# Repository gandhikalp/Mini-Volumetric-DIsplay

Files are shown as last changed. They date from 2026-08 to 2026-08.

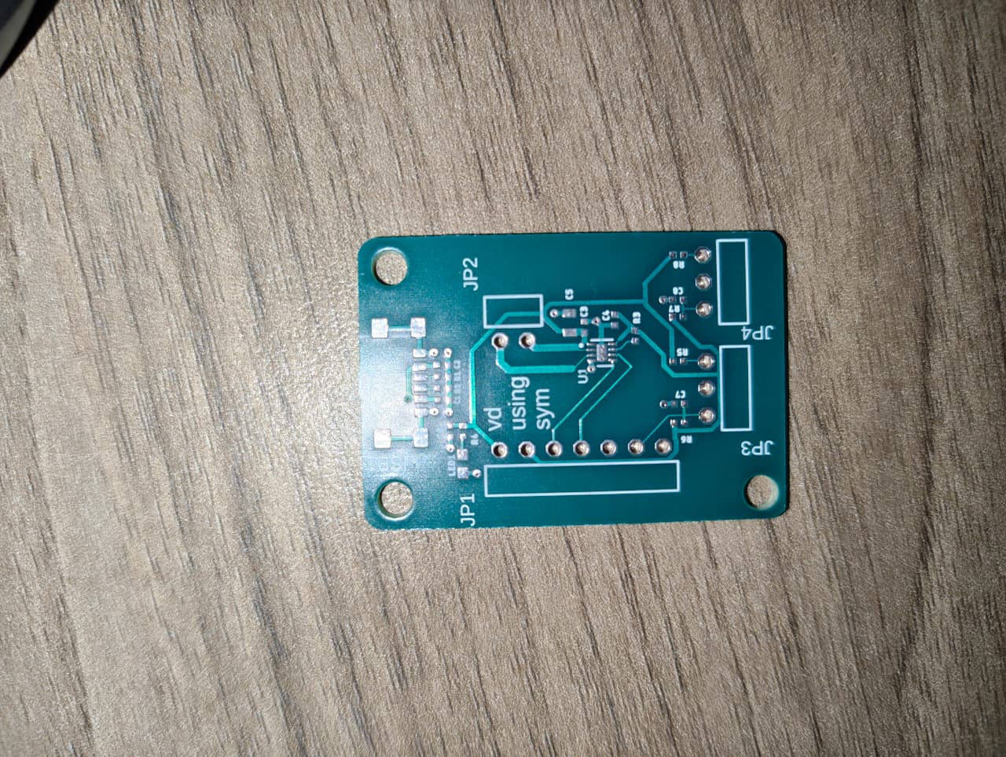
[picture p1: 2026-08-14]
hardware/pcb/Photos/When it arrived after fabrication.jpeg

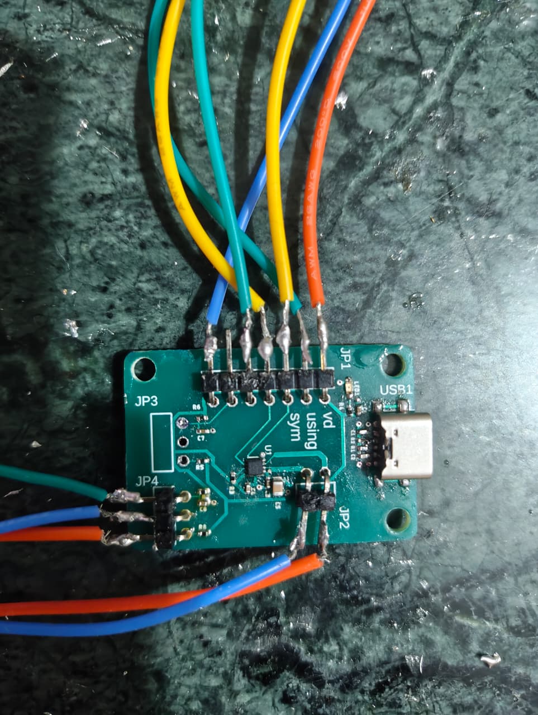
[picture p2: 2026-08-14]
hardware/pcb/Photos/Assembled PCB.jpeg

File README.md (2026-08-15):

# Volumetric Display Prototype

A swept-volume volumetric display built from scratch using a 
scotch yoke mechanism, custom SMT PCB, and Waveshare ESP32-S3-Matrix.

**Status:** Electronics and PCB tested ✅ | Mechanical assembly pending 🔄

> ⚠️ **Note:** This is an active prototype project. Thus, Hardware files and firmware are subject to rapid iterations.
---

## What This Is

A proof-of-concept volumetric display similar in basic principle to the 
Voxon VX1. An 8×8 RGB LED matrix sweeps vertically at ~16Hz 
using a scotch yoke mechanism, creating a 3D persistence-of-vision 
image visible from multiple angles.\
It is highly inspired from [Matthew Lim's video](https://youtu.be/KgT20tHpk1g?si=lmqNyyaOBYBv9zQp) on youtube about mini volumetric display.

---

## Hardware

| Component | Details |
|---|---|
| Microcontroller | Waveshare ESP32-S3-Matrix (8×8 RGB LED matrix) |
| Custom PCB | 2-layer SMT, designed in Fusion 360, fabricated by Lion Circuits |
| Motor | GA12-N20 6V 1000RPM DC motor |
| Motor driver | DRV8838DSGR (on the PCB) |
| Position sensing | Dual ITR-9606 opto interrupters |
| Mechanism | Scotch yoke |
| PCB size | 27.5mm × 40mm |

---

## Firmware Architecture 

Core 0 (real-time):\
→ Motor PWM control via DRV8838\
→ Dual opto interrupt handling\
→ Slice timing calculation

Core 1 (non-critical):\
→ WiFi connection\
→ OTA wireless firmware updates\
→ Web debug dashboard

---

## Current Progress

- [DONE] Custom PCB designed, fabricated, assembled
- [DONE] Motor control verified (3 speeds via PWM)
- [DONE] Dual opto interrupter timing verified
- [DONE] Dual-core firmware with WiFi debug dashboard
- [DONE] OTA wireless firmware updates
- [PENDING] Desgining cad v_2
- [PENDING] Mechanical assembly
- [PENDING] Volumetric slice display firmware

---

## Repository Structure

```text
├── hardware/
│   ├── pcb/               # Gerber Files, BOM, schematic, PCB photos
│   └── cad/        
│       ├── failed_design/     # First design + notes on why it failed
│       └── current_design/    # Current redesigned mechanism
├── firmware/              # Arduino IDE sketches
├── build_log/                  # Build log, images
└── references/            # Inspiration and related work
```
---

## PCB

Custom 2-layer controller board handling:
- USB-C power input with proper CC resistor negotiation(5.1k ohms resistors)
- DRV8838DSGR motor driver (1.8A capable)
- Dual opto interrupter interface circuits
- 7-pin interface to ESP32 board
- Status LED

Fabricated by Lion Circuits, India.

---

## Why **Scotch Yoke** Mechanism?

Unlike rack-and-pinion (used in Matthew Lim's build) and slider crank mechanism (which also used for converting circular motion into linear reciprocating motion), 
Scotch Yoke produces Simple Harmonic Motion:
- Screen dwells longer at extremes → better brightness distribution
- No backlash at direction reversal
- Smoother reversal → lower vibration
- Mathematically clean position from sin(angle)

---

## Build Log

See [build_log.md](build_log/build_log.md)

---

## Related Work

- [Matthew Lim's mini volumetric display](https://youtu.be/KgT20tHpk1g?si=lmqNyyaOBYBv9zQp)
- [Voxon Photonics VX1/VX2](https://voxon.co)

---

## Author

Gandhi Kalp — 2nd year B.Tech Civil Engineering, IIT ISM Dhanbad  
Interests: Robotics, Embedded Systems, IoT, ML and Automation

Check my [LinkedIn](https://www.linkedin.com/in/gandhikalpniravkumar/?skipRedirect=true)

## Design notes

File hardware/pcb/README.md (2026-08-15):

# PCB of Mini VLD using SYM

Think of this custom PCB as the central hub of the project. It sits directly between the power supply, the DC motor, the optical sensors, and the ESP32-S3. 

By taking care of all the messy power routing and distribution, it lets the ESP32 just sit back and focus entirely on the computation. It also features an onboard DRV8838 motor driver. Since the ESP32 can only output weak, low-voltage instructions, it takes all logic signals and then safely delivers the required high current to spin the motor.

---

## Technical Specifications

| Parameter | Specification |
| :--- | :--- |
| **Project Name** | vd_using_sym |
| **Dimensions** | 27.5 mm × 40.0 mm |
| **Layer Count** | 2 Layers |
| **Thickness** | 1.6 mm |
| **Substrate** | FR4 (Tg 130°C) |
| **Solder Mask** | Green |
| **Silkscreen** | White (Single Side) |
| **Surface Finish** | HASL |
| **Fabricator** | Lion Circuits (India) - IPC Class 2 |

---

## System Architecture

The board takes 5V from the USB-C port to directly power the motor driver and the ESP32-S3. To save space, it does not use an onboard 3.3V regulator. Instead, the ESP32 sends regulated 3.3V *back* to the mainboard to power the logic, sensors, and status LED.

```mermaid
graph TD
    USB[USB-C 5V] --> 5V_RAIL[5V Rail]
    5V_RAIL --> DRV[DRV8838 Driver]
    5V_RAIL --> ESP[Waveshare ESP32-S3]
    
    ESP -->|3.3V Return| 3V3_RAIL[3.3V Rail]
    3V3_RAIL -->|Logic Power| DRV
    3V3_RAIL -->|Logic Power| SENSORS[Opto Sensors]
    
    ESP -->|Motor Control| DRV --> MOTOR[N20 DC Motor]
    SENSORS -->|Timing Interrupts| ESP
```
---
## Hardware Pinout Map

### Main Header (`JP1` — 7-Pin Interconnect)
*Connects the PCB to the moving Waveshare ESP32-S3 board.*

| Pin # | Label | Direction | Target | Function |
| :---: | :--- | :---: | :--- | :--- |
| **1** | `GND` | Power | System Ground | Common Ground Reference |
| **2** | `O1` (OPTO1) | Output | `GPIO4` | Top Dead Centre (TDC) Trigger |
| **3** | `O2` (OPTO2) | Output | `GPIO5` | Bottom Dead Centre (BDC) Trigger |
| **4** | `MOTOR_DIR` | Input | `GPIO6` | Motor Direction Control |
| **5** | `MOTOR_PWM` | Input | `GPIO7` | Motor Speed Control |
| **6** | `+3.3V` | Input | 3.3V Rail | 3.3V **returned** from Waveshare LDO |
| **7** | `+5V` | Output | 5V Rail | Main 5V Supply to Waveshare |
---

## Key Design Features

*   **Efficient Motor Control:** Uses a tiny DRV8838 driver to deliver maximum power to the motor without wasting voltage or generating excess heat.

*   **Hardware Debouncing:** An onboard filter (using 100nf capacitor and 10kohms resistor) physically smooths out messy sensor signals before they reach the ESP32.

*   **Safe Sensor Logic:** Sensor voltages are tied to 3.3V, protecting the ESP32 pins from any damage.

*   **Power-Only USB-C:** Dedicated strictly to 5V power delivery.

---
## Testing & Validation

The Board has been fully assembled and all the components are tested also.

*   ✅ **Power Rail:** 5V successfully delivered to the motor driver and ESP; status LED active.
*   ✅ **Logic Control:** 3.3V successfully returning from the ESP to power the logic layer.
*   ✅ **Motor Control:** DRV8838 driving the N20 motor at variable PWM speeds with forward/reverse direction control.
*   ✅ **Sensor Interrupts:** Opto-interrupters triggering clean, hardware-debounced signals on the ESP pins.

---

## Manufacturing & Assembly

All necessary files to fabricate and assemble this board are located in the [Manufacturing files](./Manufacturing%20files/) folder:

*   **Gerbers & NC Drill Files:** Ready for standard 2-layer fabrication.
*   **BOM (Bill of Materials):** Complete list of passives, headers, and ICs.

> **Next Step:** To see the C++ code that runs on the ESP32-S3 board to test this PCB, head over to the [Firmware Directory](../../firmware/).
---

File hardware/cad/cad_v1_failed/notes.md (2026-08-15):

# CAD v1 — Design Failures and Lessons Learned

This folder preserves the first mechanical design iteration.
And i really believe that documenting failures is as important as documenting successes.
These are the exact problems found and the decisions made.

---

## Failure 1 — Wire Routing Holes Too Small

### What Was Designed
Small rectangular holes were made to fit in the opto interruptors but they were small that the wires wouldn't go in them.

### What Was Wrong
The hole area was insufficient for:
- The opto interrupter body to pass through for mounting
- Multiple silicone wires to route cleanly together

The opto interrupters (ITR-9606) could not be inserted
through the holes into their mounting brackets as intended.
Wires had to be forced through, risking insulation damage
at the sharp hole edges.

### Root Cause
Holes were sized purely for physical dimensions of the opto interruptor without
accounting for:
- Wire diameter
- Wire bundle diameter when multiple wires grouped together
- Assembly clearance needed during build

### To be fixed In v2
- Opto mounting holes enlarged to fit ITR-9606 body with
  0.5mm clearance on each side
- Take in account for the diameter of the wires also

---

## Failure 2 — Bottom Linear Guide Too Short (Yoke Escape)

### What Was Designed
Two rectangular guide blocks — one at top, one at bottom
of the frame — to constrain the yoke slider to vertical
motion only. The yoke has rectangular rails that slide
through these guide blocks.

### What Was Wrong
The bottom guide block was too short in the vertical
direction. At the top of the yoke's travel stroke,
the bottom rails of the yoke slider exited the bottom
guide block completely. Once outside the guide, the
yoke had no constraint at the bottom — it began to
wobble and rotate around the crank pin axis.

Specifically:
- Bottom guide block height: too short
- Bottom rail fully
  exited guide block → zero constraint → wobble

### Why This Wasn't Caught In Simulation
The joints in Fusion 360 were set up to only allow
vertical slider motion regardless of physical geometry.
The simulation showed correct motion because the joints
enforced it mathematically — not because the geometry
actually constrained it.

Real-world: once the rail exits the block, no constraint.
Simulation: joint still enforces linear motion regardless.

This is the difference between kinematic simulation
and real mechanical constraint.

### Root Cause
Failure to verify that the guide block remained engaged
with the rail throughout the FULL stroke of travel.

The check that was missed:
Does any part of the rail remain outside
the guide block during the motion? Answer was **YES** for the bottom block.

### The Rule This Establishes
Guide block must remain engaged with rail by at least
one full block-length at every point in the stroke.

Minimum rail length below slot =
  bottom guide block height
  + full stroke length (20mm)
  + safety margin (5mm)  
  = 25mm minimum

### To be fixed in v2
- Bottom guide block height increased significantly
- Rail length extended downward to maintain engagement
  at full top-dead-centre position
- Added explicit check in Fusion: at top of stroke,
  measured remaining rail inside guide block
  Result: 8mm still engaged at worst case ✅
- Added fillet at guide block entry to smooth
  any edge contact at extreme positions

---

## Summary Table

| Failure | Component | Root Cause | Fix To Be Applied |
|---|---|---|---|
| Holes too small | Wire/opto routing | No clearance for wire diameters | Enlarged holes |
| Yoke escapes guide | Bottom guide block | Guide too short for full stroke | Longer block + longer rails |

---

## Key Lessons
- Always check mechanism at EXTREME positions
not just the neutral/mid position.
- Fusion joints enforce motion mathematically
Real geometry must also enforce it physically. 
- Simulate ≠ works in real life
- Any hole a component passes through needs
component dimension + clearance.
- Size consideration should be done for wire diameter also.
- For sliding mechanisms: Engagement length remaining at worst case
must be verified explicitly before printing
---
### What Was Preserved Here

The original Fusion 360 design files (`.f3d` and `.step`) are included in this folder for archival purposes, but they have been entirely **SUPERSEDED** by v2.

What is preserved in this document:
- This written failure analysis
- The specific measurements that were wrong
- The design decisions made as a result
- The lessons applied to v2

### Failure documentation is part of the engineering record. Version 2 exists because version 1 failed and was analyzed honestly. 
---

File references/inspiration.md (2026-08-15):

# References & Inspiration

This prototype was built on the foundation of existing research, open-source projects, and technical documentation in the volumetric display technology. 

## Primary Inspiration

   *   [Watch Matthew Lim's Video Here](https://youtu.be/KgT20tHpk1g?si=lmqNyyaOBYBv9zQp)

## Commercial Products

*   **Voxon Photonics (VX1 & VX2):** The industry pioneers in swept-volume volumetric displays, serving as the ultimate benchmark for mechanical persistence-of-vision (POV) 3D technology. 
    *   **VX1:** The original flagship model that proved the concept, utilizing a linear reciprocating (up-and-down) screen paired with an ultra-fast DLP projector. 
    *   **VX2:** A massive architectural upgrade over the VX1. Instead of a bouncing screen, the VX2 relies on a high-speed rotating LED matrix (VLED Engine) that spins at 900 RPM. This rotational concept is vastly superior, allowing the machine to run quieter, scale larger, and generate up to 8 million voxels while refreshing 30 full 3D volumes every second.

## Technical References & Datasheets

I referenced official datasheets to calculate component values and verify power limits for the custom PCB. Copies of these files are saved in the [Datasheets directory](../hardware/Datasheets_of_major_components_used/). 

*   **Waveshare ESP32-S3-Matrix:** Used for GPIO pinouts, onboard 3.3V LDO specs, and LED matrix timing. Here's the link for it => [Waveshare ESP32-S3 Matrix](https://docs.waveshare.com/ESP32-S3-Matrix)
*   **Texas Instruments DRV8838:** Used to check motor driver power limits and bypass capacitor requirements.
*   **Everlight ITR-9606 Opto-interrupter:** Used to calculate the 100Ω current-limiting resistor for the IR LED.

## Tools Used

*   **Autodesk Fusion 360:** Used for both mechanical 3D modeling of the Scotch Yoke mechanism and the 2D schematic/PCB layout.

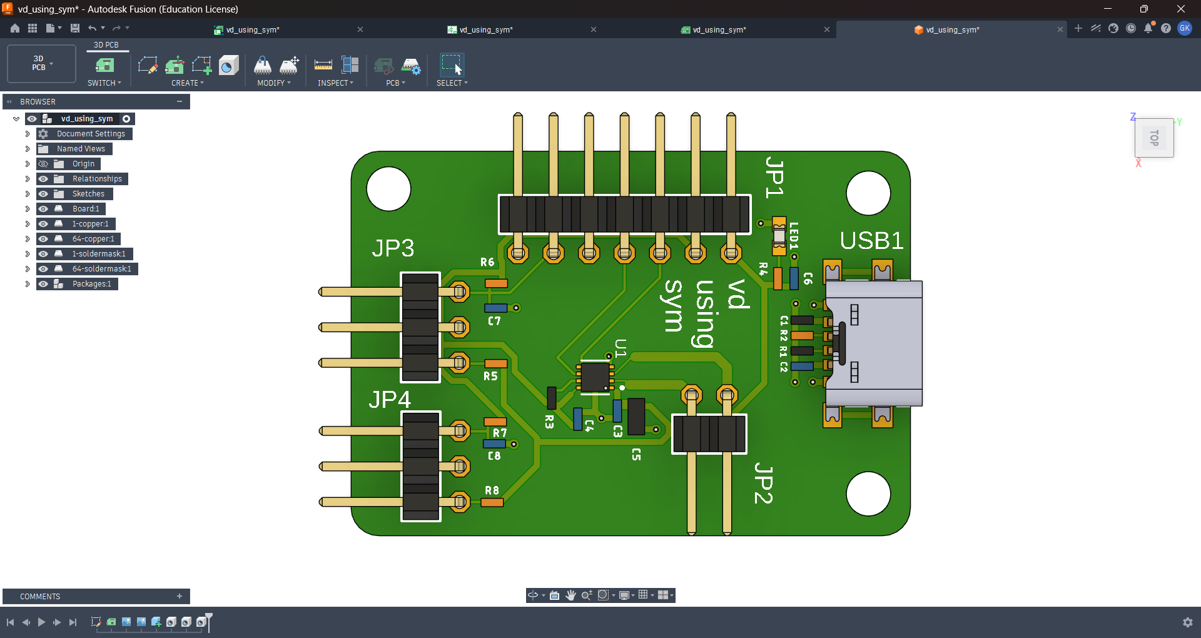
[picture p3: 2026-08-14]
hardware/pcb/Photos/frontside_of_pcb.png

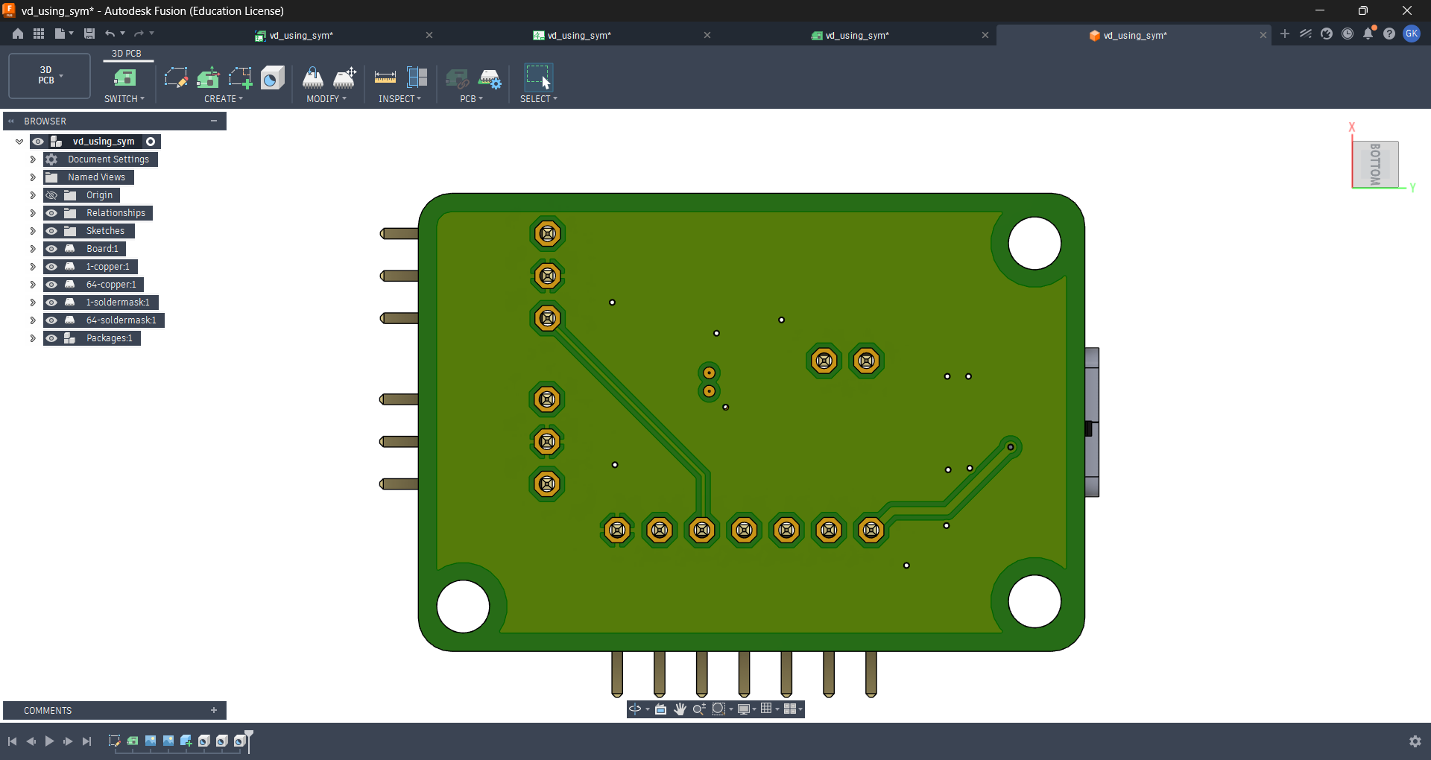
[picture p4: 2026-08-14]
hardware/pcb/Photos/backside_of_pcb.png

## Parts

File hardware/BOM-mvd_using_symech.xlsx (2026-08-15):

NAME | LINK | PRICE FOR SINGLE UNIT( in Rupees) | QTY | FINAL PRICE(inc gst and shipping charges)(in Rupees) | REMARK | USED/ NOT USED
Waveshare ESP32-S3 Development Board, Onboard 8×8 RGB LED Matrix and QMI8658C Attitude Sensor, Supports Wi-Fi and Bluetooth LE, ESP32 Development Board | https://robu.in/product/waveshare-esp32-s3-development-board-onboard-8x8-rgb-led-matrix-and-qmi8658c-attitude-sensor-supports-wi-fi-and-bluetooth-le-esp32-dev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 | 1130 | 1 | 1130 |  | USED
N20 6V 1000RPM Micro Metal Gear Motor | https://ifuturetech.org/product/ga12-n20-6v-1000rpm-micro-dc-metal-gear-motor/ | 249 | 1 | 274 | 50/- shippping charges on this site divided into 2 for both the components, thus 25 each(249 + 25) | USED
623ZZ Radial Ball Bearing for 3D Printer/ Robot (4Pcs) | https://robu.in/product/radial-ball-bearing-623zz-3d-printer-robot-4pcs/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 | 82 | 1 | 82 |  | USED ONLY 1
ITR-9606 Opto Interruptor Optical Sensor DIP - 4 | https://ifuturetech.org/product/itr-9606-opto-interrupter-optical-sensor-dip-4/ | 30 | 2 | 85 | 50/- shippping charges on this site divided into 2 for both the components, thus 25 each(30x2+25) | USED
INVENTO 2pcs EN31 Rustproof Steel Smooth Rod 6mm OD 100mm (0.1 mtr) Long for CNC Robotics Machines DIY Projects | https://www.amazon.in/INVENTO-Rustproof-Robotics-Machines-Projects/dp/B08BGBMGD2 | 299 | 1 | 304 |  | NOT USED
LM6UU 6mm Linear Motion Bearing | https://robu.in/product/lm6uu-6-mm-linear-bearings-linear-motion-bearing/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 | 49 | 4 | 196 |  | NOT USED
28AWG High Quality Ultra Flexible Silicone Wire – Green | https://robu.in/product/high-quality-ultra-flexible-28awg-silicone-wire-1000m-green/ | 7 | 2 | 14 |  | USED
28AWG High Quality Ultra Flexible Silicone Wire – Blue | https://robu.in/product/high-quality-ultra-flexible-28awg-silicone-wire-1000m-blue/ | 7 | 2 | 14 |  | USED
26AWG High Quality Ultra Flexible Silicone Wire – Yellow | https://robu.in/product/high-quality-ultra-flexible-26awg-silicone-wire-1000m-yellow/ | 7 | 2 | 14 |  | USED
26AWG High Quality Ultra Flexible Silicone Wire – Red | https://robu.in/product/high-quality-ultra-flexible-26awg-silicone-wire-1000m-red/ | 7 | 2 | 14 |  | USED
 |  |  | TOTAL PRICE | 2127

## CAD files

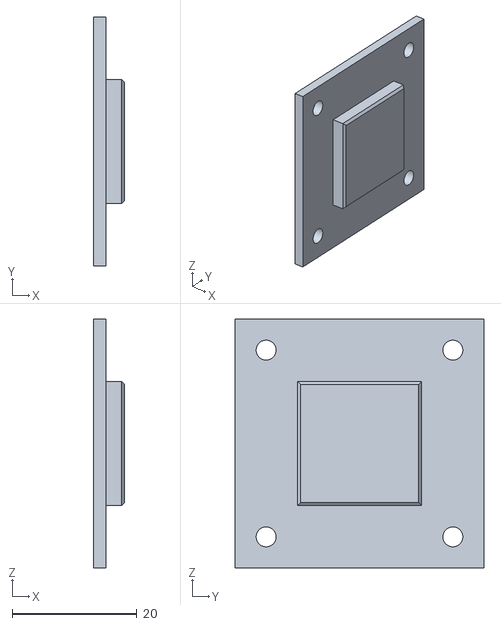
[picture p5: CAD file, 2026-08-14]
hardware/cad/cad_v1_failed/Individual stl files of failed version/MountCB.stl
5.00 x 40.0 x 40.0

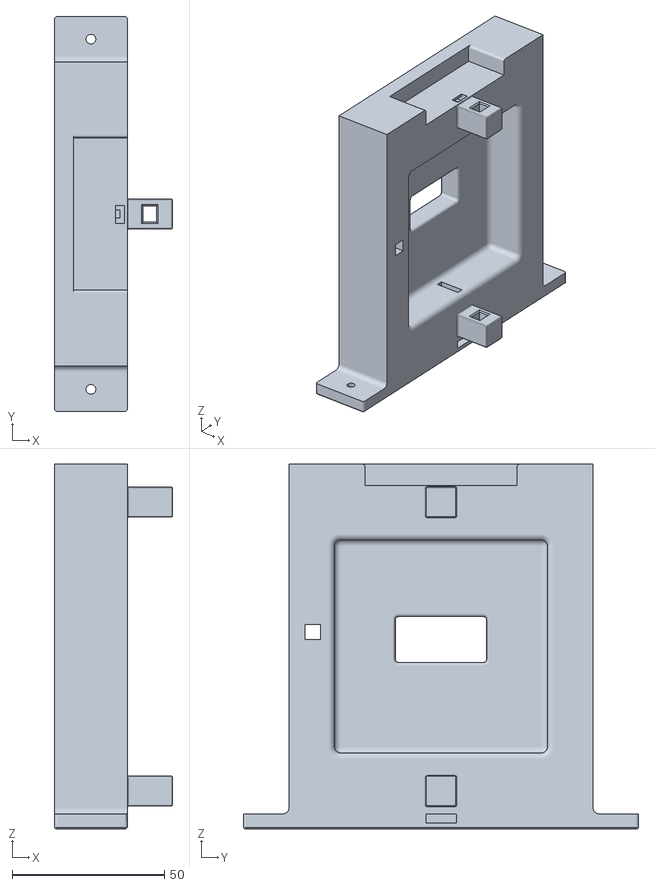
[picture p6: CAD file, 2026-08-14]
hardware/cad/cad_v1_failed/Individual stl files of failed version/Crank Keeper.stl
38.8 x 130.0 x 120.0

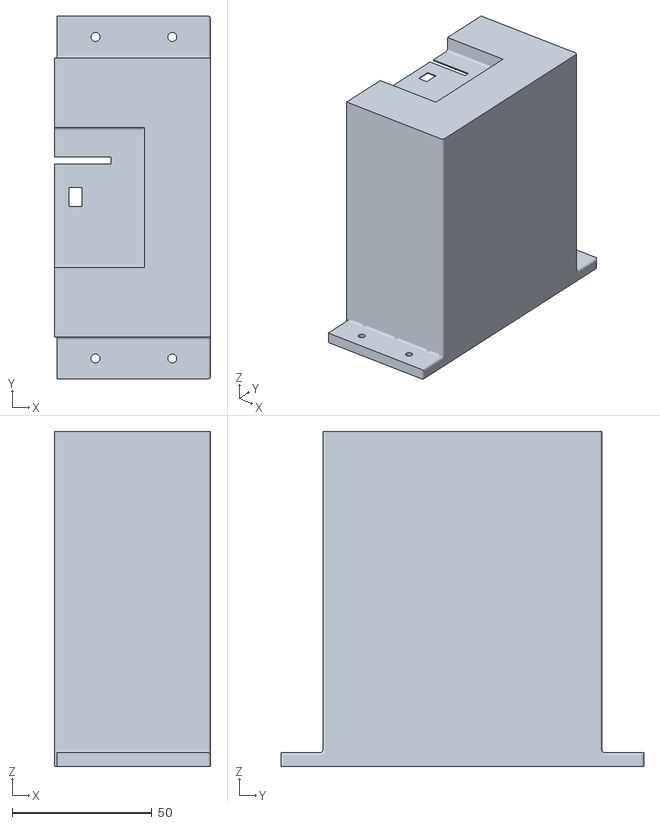
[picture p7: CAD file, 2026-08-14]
hardware/cad/cad_v1_failed/Individual stl files of failed version/Outer Body.stl
56.0 x 130.0 x 120.0

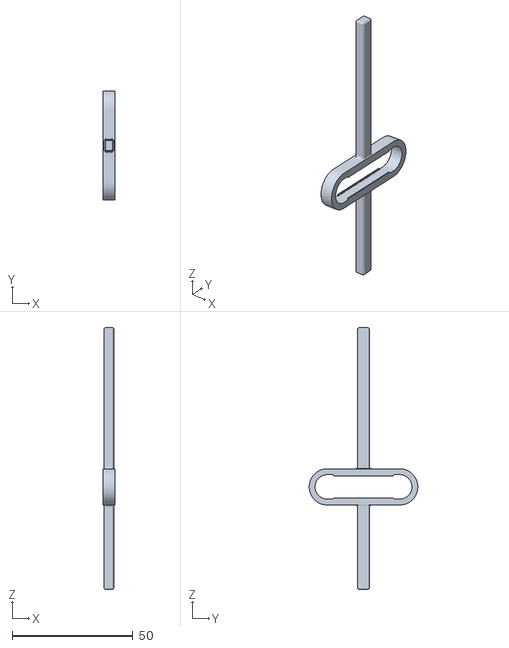
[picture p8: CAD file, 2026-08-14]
hardware/cad/cad_v1_failed/Individual stl files of failed version/Yoke.stl
5.00 x 45.0 x 108.5

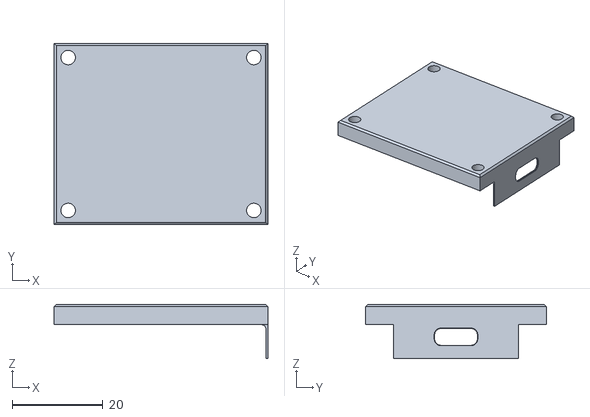
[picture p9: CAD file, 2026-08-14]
hardware/cad/cad_v1_failed/Individual stl files of failed version/PCB Mount.stl
47.2 x 40.0 x 12.0

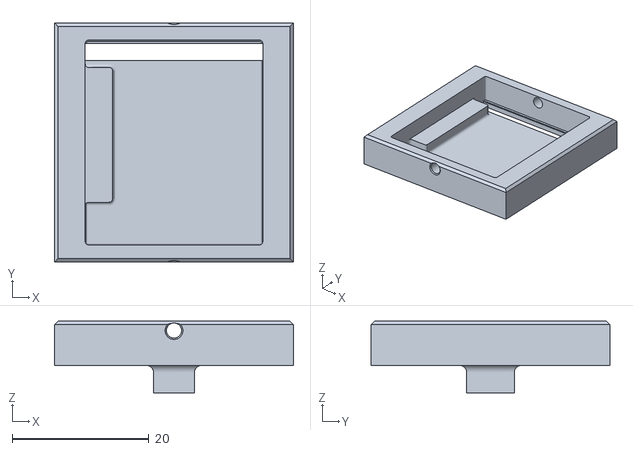
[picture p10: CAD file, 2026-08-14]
hardware/cad/cad_v1_failed/Individual stl files of failed version/Esp mount.stl
35.0 x 35.0 x 10.5

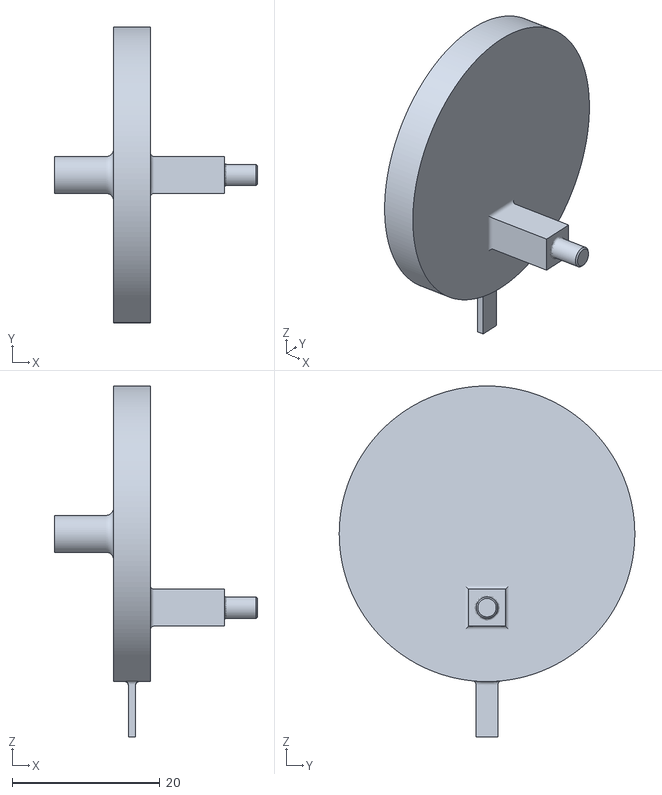
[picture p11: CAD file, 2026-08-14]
hardware/cad/cad_v1_failed/Individual stl files of failed version/Crank.stl
27.5 x 40.0 x 47.5

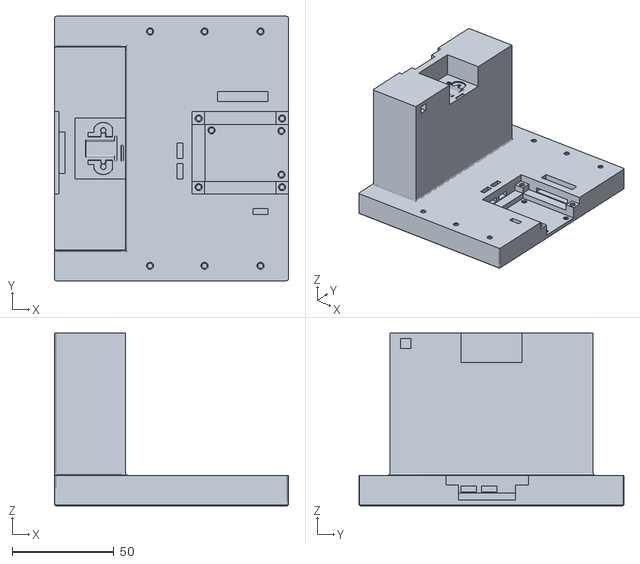
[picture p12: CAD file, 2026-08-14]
hardware/cad/cad_v1_failed/Individual stl files of failed version/Base.stl
115.0 x 130.0 x 84.8

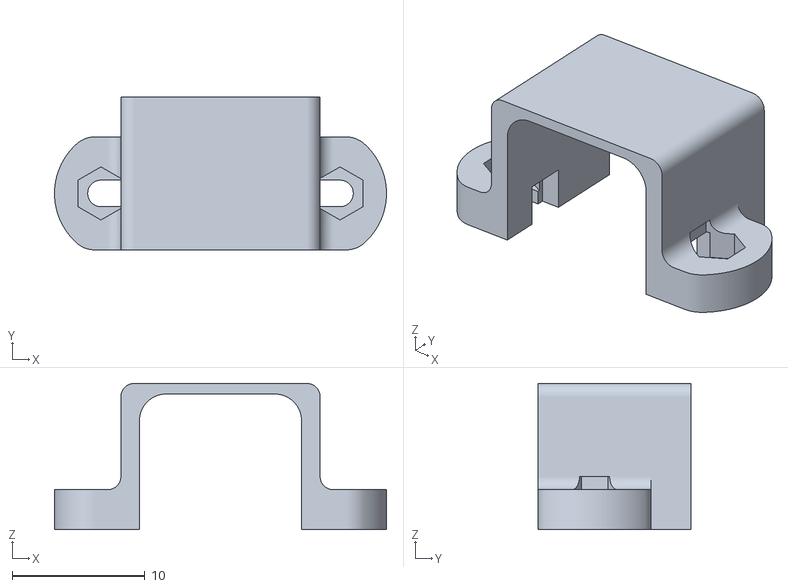
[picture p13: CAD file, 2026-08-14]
hardware/cad/cad_v1_failed/Individual stl files of failed version/Motor Mount.stl
25.0 x 11.5 x 11.0

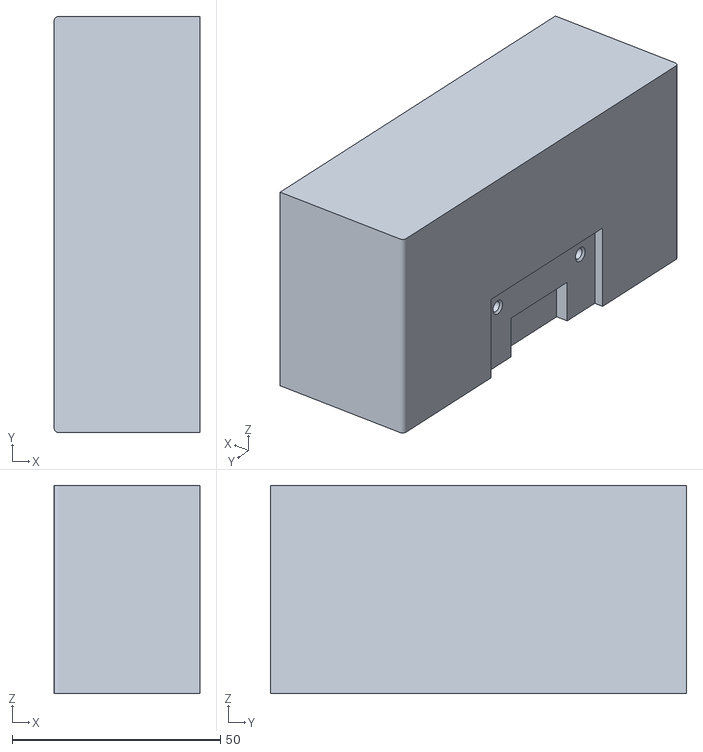
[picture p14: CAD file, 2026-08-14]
hardware/cad/cad_v1_failed/Individual stl files of failed version/Cover.stl
35.0 x 100.0 x 50.0

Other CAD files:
hardware/pcb/PCB Layout/vd_using_sym.f3z

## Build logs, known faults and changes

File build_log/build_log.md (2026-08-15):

# Build Log

## AUG 2026:
1.  Tested and validated all the components and the PCB  by temporary soldering all of them.
2.  Tested the cad_v1 after 3d printing them and validated its failure. 

---
## JULY 2026:
1. Designed the cad_v1 after learning cad on fusion and then 3D printed the  parts.
2. PCB arrived after given for fabrication to LionCircuits.

---
## JUNE 2026:
1. Designed the schematic and the PCB layout in Fusion 360.
2. Ordered the required components for the PCB(the BOM is already there in the [Manufacturing Files](../hardware/pcb/Manufacturing%20files/) folder in the zipped file.)
3. Learnt PCB Designing in Fusion 360.
4. Ordered other pre planned components required for the project(The BOM for these components is already there in the [hardware](../hardware/) folder of this repo / Alternatively you can also access it from [**_here_**](../hardware/BOM-mvd_using_symech.xlsx)).

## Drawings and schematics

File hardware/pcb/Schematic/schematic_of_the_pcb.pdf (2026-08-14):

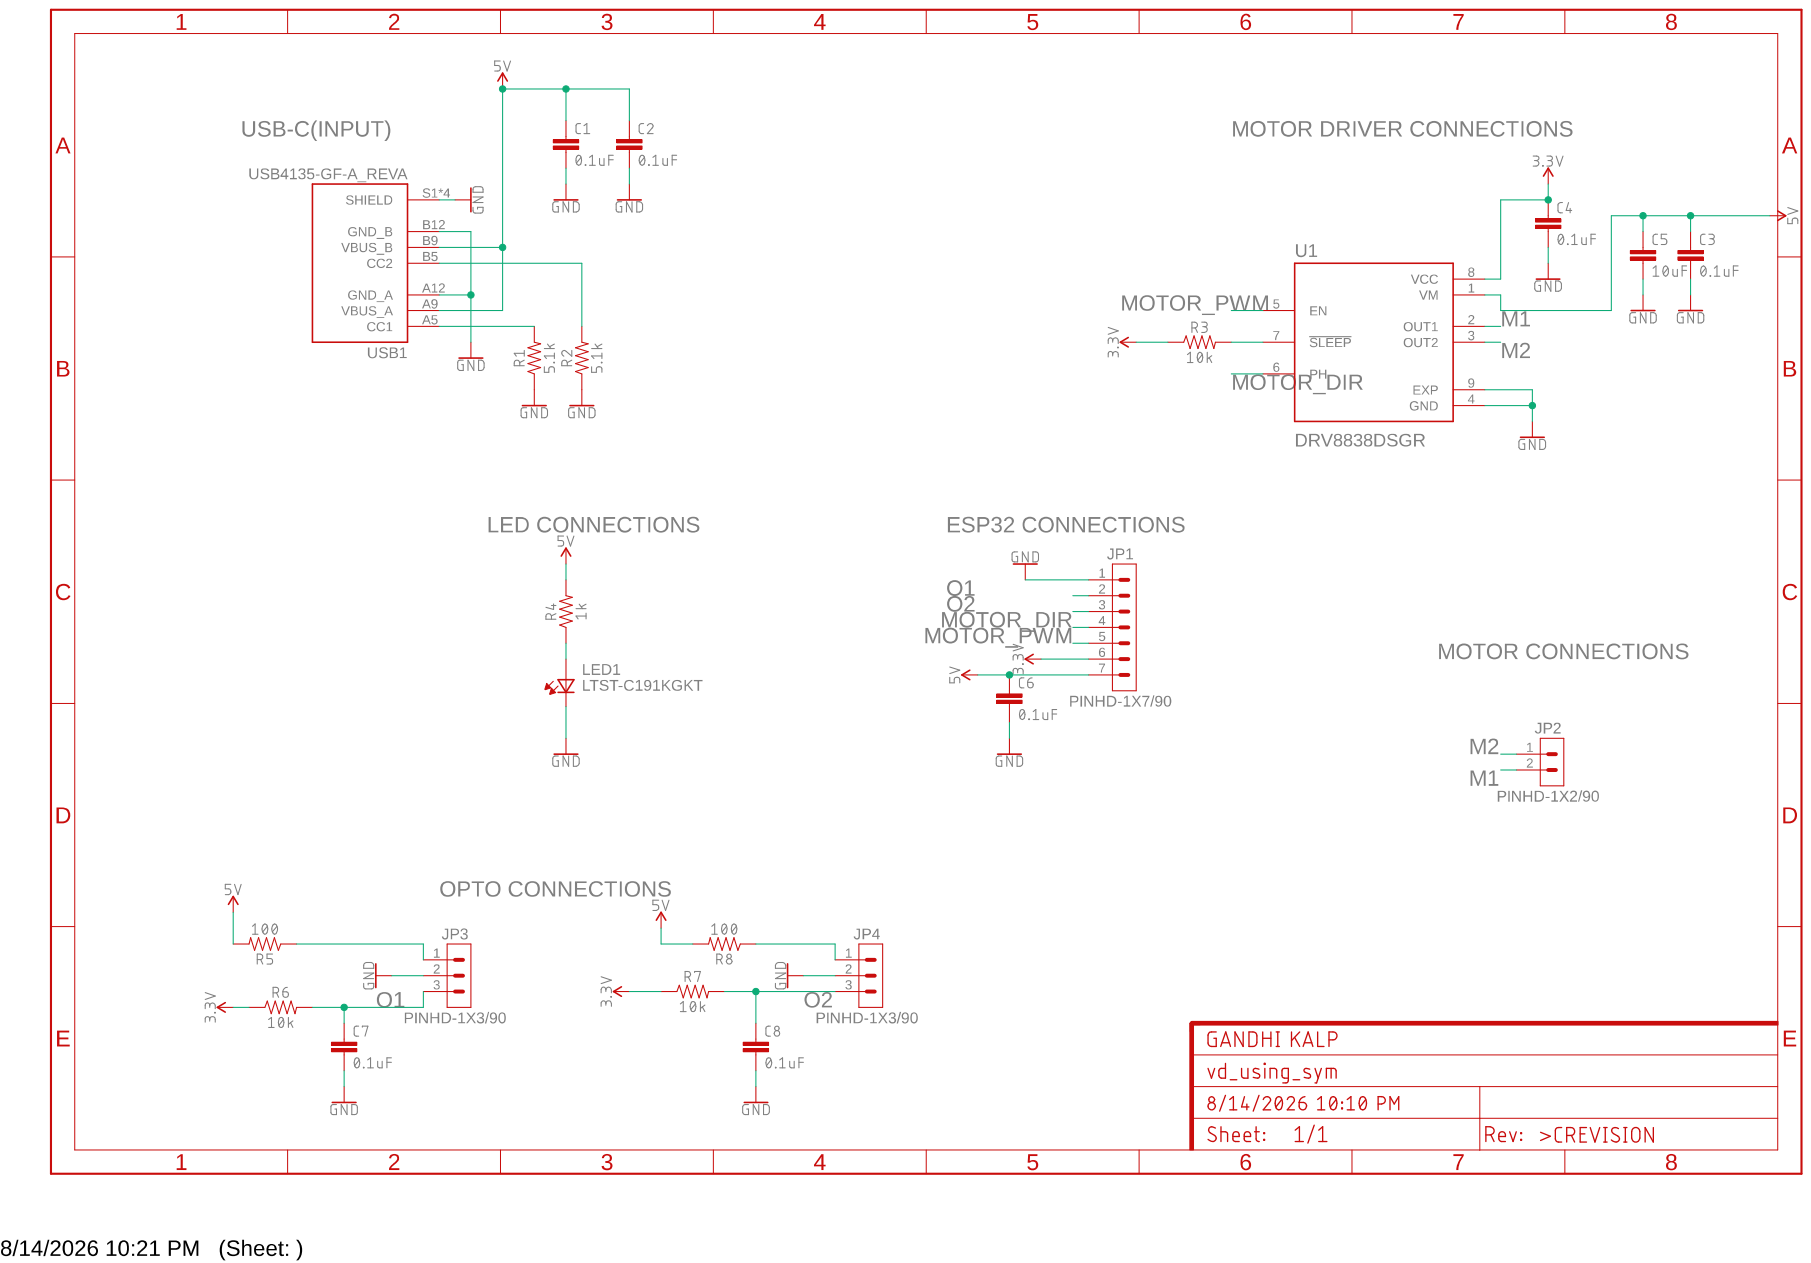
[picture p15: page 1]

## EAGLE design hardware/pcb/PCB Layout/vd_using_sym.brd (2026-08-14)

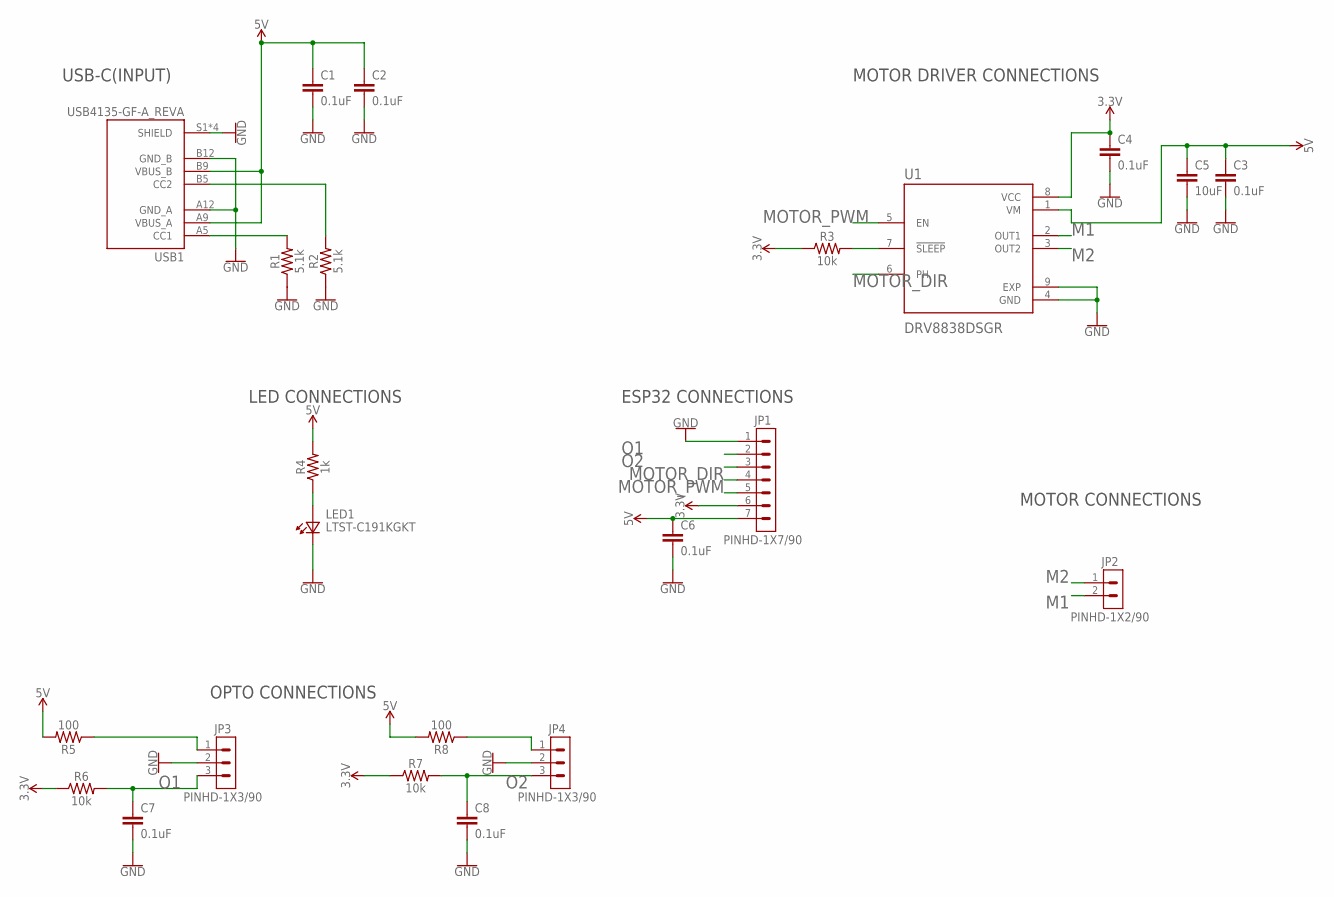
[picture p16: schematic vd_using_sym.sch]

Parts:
C1, C2, C3, C4, C6, C7, C8: 0.1uF; 0402-TIGHT
C5: 10uF; 0805
JP1: PINHD-1X7/90; 1X07_90
JP2: PINHD-1X2/90; 1X02_90
JP3, JP4: PINHD-1X3/90; 1X03_90
LED1: LTST-C191KGKT; 0603
R1, R2: 5.1k; 0402-TIGHT
R3, R6, R7: 10k; 0402-TIGHT
R4: 1k; 0402-TIGHT
R5, R8: 100; 0402-TIGHT
U1: DRV8838DSGR; SON50P200X200X80-9N
USB1: USB4135-GF-A_REVA; GCT_USB4135-GF-A_REVA

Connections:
3.3V: C4.1, JP1.6, R3.1, R6.1, R7.1, U1.8 (VCC)
5V: C1.1, C2.1, C3.1, C5.1, C6.1, JP1.7, R4.2, R5.2, R8.2, U1.1 (VM), USB1.A9 (VBUS_A), USB1.B9 (VBUS_B)
GND: C1.2, C2.2, C3.2, C4.2, C5.2, C6.2, C7.2, C8.2, JP1.1, JP3.2, JP4.2, LED1.1 (K2), R1.1, R2.1, U1.4 (GND), U1.9 (EXP), USB1.A12 (GND_A), USB1.B12 (GND_B), USB1.S1 (SHIELD), USB1.S2 (SHIELD), USB1.S3 (SHIELD), USB1.S4 (SHIELD)
M1: JP2.2, U1.2 (OUT1)
M2: JP2.1, U1.3 (OUT2)
MOTOR_DIR: JP1.4, U1.6 (PH)
MOTOR_PWM: JP1.5, U1.5 (EN)
unnamed: R1.2, USB1.A5 (CC1)
unnamed: R2.2, USB1.B5 (CC2)
unnamed: R3.2, U1.7 (!SLEEP)
unnamed: LED1.2 (A2), R4.1
unnamed: JP3.1, R5.1
unnamed: JP4.1, R8.1
O1: C7.1, JP1.2, JP3.3, R6.2
O2: C8.1, JP1.3, JP4.3, R7.2

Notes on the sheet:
USB-C(INPUT)
MOTOR DRIVER CONNECTIONS
ESP32 CONNECTIONS
LED CONNECTIONS
MOTOR CONNECTIONS
OPTO CONNECTIONS

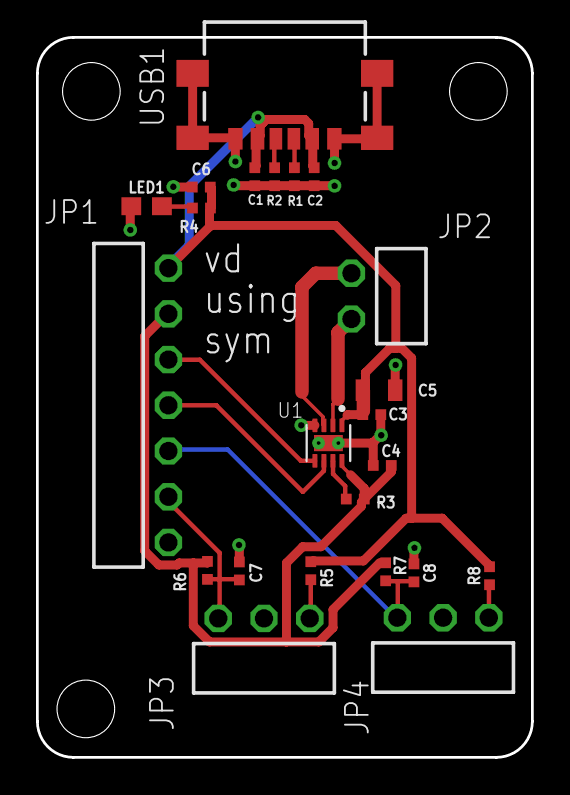
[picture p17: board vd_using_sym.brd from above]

Board: 2 copper layers, 27.5 x 40.0 mm, 23 parts (0 on the bottom side), 15 nets.

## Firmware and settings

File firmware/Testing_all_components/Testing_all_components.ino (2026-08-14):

#include <WiFi.h>
#include <ArduinoOTA.h>
#include <WebServer.h>
#include <Adafruit_NeoPixel.h>

// ═══════════════════════════════════════════
// WIFI CREDENTIALS
// ═══════════════════════════════════════════
const char* ssid     = "KP";
const char* password = "gandhi16";

// ═══════════════════════════════════════════
// PIN DEFINITIONS 
// ═══════════════════════════════════════════
#define MOTOR_PWM_PIN   7    // → DRV8838 EN pin 
#define MOTOR_DIR_PIN   6    // → DRV8838 PH pin
#define OPTO1_PIN       4    // → ITR-9606 #1 signal 
#define OPTO2_PIN       5    // → ITR-9606 #2 signal 
#define LED_MATRIX_PIN  14   // → 8x8 LED matrix (internal)
#define NUM_LEDS        64   // 8x8 = 64 total LEDs

// ═══════════════════════════════════════════
// LED MATRIX SETUP
// ═══════════════════════════════════════════
Adafruit_NeoPixel matrix(NUM_LEDS, LED_MATRIX_PIN, NEO_GRB + NEO_KHZ800);

// Colour definitions
#define OFF    matrix.Color(0,  0,  0)
#define GREEN  matrix.Color(0,  20, 0)    // dim green
#define RED    matrix.Color(20, 0,  0)    // dim red
#define BLUE   matrix.Color(0,  0,  20)   // dim blue
#define YELLOW matrix.Color(20, 15, 0)    // dim yellow
#define WHITE  matrix.Color(10, 10, 10)   // dim white
#define ORANGE matrix.Color(20, 8,  0)    // dim orange

// ═══════════════════════════════════════════
// SHARED VARIABLES
// ═══════════════════════════════════════════
volatile unsigned long revPeriod    = 0;
volatile unsigned long lastOpto1    = 0;
volatile unsigned long lastOpto2    = 0;
volatile int           currentRPM   = 0;
volatile unsigned long opto1Count   = 0;
volatile unsigned long opto2Count   = 0;
volatile bool          opto1Flash   = false;
volatile bool          opto2Flash   = false;
volatile bool          motorRunning = false;
volatile int           motorPWM     = 0;

// ═══════════════════════════════════════════
// LEDC (PWM) SETUP FOR MOTOR
// ═══════════════════════════════════════════
#define PWM_CHANNEL    0
#define PWM_FREQUENCY  5000     // 5kHz PWM frequency
#define PWM_RESOLUTION 8        // 8-bit = 0 to 255

// ═══════════════════════════════════════════
// INTERRUPT HANDLERS (WITH SOFTWARE DEBOUNCE)
// ═══════════════════════════════════════════
void IRAM_ATTR opto1ISR() {
    unsigned long now = micros();
    // DEBOUNCE: Ignore flickers faster than 5ms (5000 microseconds)
    // 5ms is fast enough to read a motor spinning at 12,000 RPM cleanly.
    if (now - lastOpto1 > 5000) { 
        revPeriod  = now - lastOpto1;
        lastOpto1  = now;
        opto1Count++;
        opto1Flash = true;
        if (revPeriod > 0) {
            currentRPM = (unsigned long)60000000 / revPeriod;
        }
    }
}

void IRAM_ATTR opto2ISR() {
    unsigned long now = micros();
    // DEBOUNCE filter for Sensor 2
    if (now - lastOpto2 > 5000) {
        lastOpto2  = now;
        opto2Count++;
        opto2Flash = true;
    }
}

// ═══════════════════════════════════════════
// MATRIX HELPER FUNCTIONS
// ═══════════════════════════════════════════
void setPixel(int row, int col, uint32_t color) {
    if (row < 0 || row > 7 || col < 0 || col > 7) return;
    int index = (row * 8) + col;
    matrix.setPixelColor(index, color);
}

void fillAll(uint32_t color) {
    for (int i = 0; i < NUM_LEDS; i++) {
        matrix.setPixelColor(i, color);
    }
}

void fillRow(int row, uint32_t color) {
    for (int col = 0; col < 8; col++) {
        setPixel(row, col, color);
    }
}

void fillCol(int col, uint32_t color) {
    for (int row = 0; row < 8; row++) {
        setPixel(row, col, color);
    }
}

// ═══════════════════════════════════════════
// UPDATE LED MATRIX — visual debug display
// ═══════════════════════════════════════════
void updateMatrix() {
    matrix.clear();

    // ── ROWS 0-1: Motor status ──
    uint32_t motorColor = motorRunning ? GREEN : RED;
    fillRow(0, motorColor);
    fillRow(1, motorColor);

    // ── ROW 2: RPM bar graph ──
    int rpmLEDs = map(currentRPM, 0, 1200, 0, 8);
    rpmLEDs = constrain(rpmLEDs, 0, 8);
    for (int col = 0; col < rpmLEDs; col++) {
        setPixel(2, col, ORANGE);
    }

    // ── ROW 3: Revolution counter ──
    int revDisplay = (opto1Count % 800) / 100;
    for (int col = 0; col < revDisplay; col++) {
        setPixel(3, col, WHITE);
    }

    // ── ROWS 4-5: Opto status ──
    if (opto1Flash) {
        fillRow(4, BLUE);
        opto1Flash = false;   
    }
    if (opto2Flash) {
        fillRow(5, YELLOW);
        opto2Flash = false;
    }

    // ── ROW 6-7: Opto count bars ──
    int o1bar = opto1Count % 8;
    int o2bar = opto2Count % 8;
    for (int col = 0; col < (int)o1bar; col++) {
        setPixel(6, col, BLUE);
    }
    for (int col = 0; col < (int)o2bar; col++) {
        setPixel(7, col, YELLOW);
    }

    matrix.show();
}

// ═══════════════════════════════════════════
// WEB DEBUG PAGE
// ═══════════════════════════════════════════
WebServer server(80);

void handleRoot() {
    String html = "<!DOCTYPE html><html><head>";
    html += "<title>VLD Test</title>";
    html += "<meta http-equiv='refresh' content='1'>";
    html += "<style>";
    html += "body{background:#0d0d0d;color:#00ff88;font-family:monospace;padding:20px;max-width:600px;}";
    html += "h1{color:#fff;} h2{color:#aaa;border-bottom:1px solid #333;padding-bottom:4px;}";
    html += ".val{color:#00ccff;font-size:1.3em;font-weight:bold;}";
    html += ".ok{color:#00ff88;} .err{color:#ff4444;} .warn{color:#ffaa00;}";
    html += ".box{background:#1a1a1a;border:1px solid #333;padding:15px;margin:10px 0;border-radius:6px;}";
    html += ".bar{background:#333;height:16px;border-radius:4px;margin-top:5px;}";
    html += ".fill{background:#00ccff;height:16px;border-radius:4px;}";
    html += "</style></head><body>";

    html += "<h1>VLD Test Dashboard</h1>";

    // Motor box 
    html += "<div class='box'><h2>Motor (GPIO7=PWM, GPIO6=DIR)</h2>";
    html += "Status: <span class='val'>";
    html += motorRunning ? "<span class='ok'>RUNNING</span>" : "<span class='err'>STOPPED</span>";
    html += "</span><br>";
    html += "PWM value: <span class='val'>" + String(motorPWM) + " / 255</span><br>";
    html += "RPM: <span class='val'>" + String(currentRPM) + "</span><br>";
    html += "Revolution period: <span class='val'>" + String(revPeriod / 1000) + " ms</span>";

    // RPM bar
    int rpmPct = constrain(map(currentRPM, 0, 1200, 0, 100), 0, 100);
    html += "<div class='bar'><div class='fill' style='width:" + String(rpmPct) + "%;background:#00ff88;'></div></div>";
    html += "</div>";

    // Opto 1 box 
    html += "<div class='box'><h2>Opto 1 — Bottom Dead Centre (GPIO4)</h2>";
    html += "Current state: <span class='val'>";
    html += digitalRead(OPTO1_PIN) == LOW ? "<span class='warn'>CLEAR</span>" : "<span class='ok'>BLOCKED</span>";
    html += "</span><br>";
    html += "Total triggers: <span class='val'>" + String(opto1Count) + "</span><br>";
    html += "Last period: <span class='val'>" + String(revPeriod / 1000) + " ms</span></div>";

    // Opto 2 box 
    html += "<div class='box'><h2>Opto 2 — Top Dead Centre (GPIO5)</h2>";
    html += "Current state: <span class='val'>";
    html += digitalRead(OPTO2_PIN) == LOW ? "<span class='warn'>CLEAR</span>" : "<span class='ok'>BLOCKED</span>";
    html += "</span><br>";
    html += "Total triggers: <span class='val'>" + String(opto2Count) + "</span></div>";

    // System box
    html += "<div class='box'><h2>System</h2>";
    html += "Uptime: <span class='val'>" + String(millis() / 1000) + " sec</span><br>";
    html += "Free heap: <span class='val'>" + String(ESP.getFreeHeap()) + " bytes</span><br>";
    html += "WiFi RSSI: <span class='val'>" + String(WiFi.RSSI()) + " dBm</span></div>";

    // LED matrix legend
    html += "<div class='box'><h2>LED Matrix Legend</h2>";
    html += "Row 0-1: GREEN=motor running, RED=stopped<br>";
    html += "Row 2: ORANGE bar = RPM (0-1200)<br>";
    html += "Row 3: WHITE = revolution count<br>";
    html += "Row 4: BLUE flash = Opto1 trigger<br>";
    html += "Row 5: YELLOW flash = Opto2 trigger<br>";
    html += "Row 6-7: Trigger count bars</div>";

    html += "<small>Auto-refreshes every 1 second</small>";
    html += "</body></html>";
    server.send(200, "text/html", html);
}

// ═══════════════════════════════════════════
// CORE 1 TASK — WiFi + OTA + Web server
// ═══════════════════════════════════════════
TaskHandle_t webTaskHandle;

void webTask(void* parameter) {
    WiFi.mode(WIFI_STA);
    WiFi.begin(ssid, password);

    int attempts = 0;
    while (WiFi.status() != WL_CONNECTED && attempts < 20) {
        delay(500);
        attempts++;
    }

    if (WiFi.status() == WL_CONNECTED) {
        fillAll(GREEN);
        matrix.show();
        delay(500);
        matrix.clear();
        matrix.show();
        
        ArduinoOTA.onStart([]() {
            ledcWrite(MOTOR_PWM_PIN, 0);
            motorRunning = false;
        });
        ArduinoOTA.begin();

        server.on("/", handleRoot);
        server.begin();
    } else {
        setPixel(0, 0, ORANGE); setPixel(0, 7, ORANGE);
        setPixel(3, 3, ORANGE); setPixel(3, 4, ORANGE);
        setPixel(4, 3, ORANGE); setPixel(4, 4, ORANGE);
        setPixel(7, 0, ORANGE); setPixel(7, 7, ORANGE);
        matrix.show();
    }

    while (true) {
        if (WiFi.status() == WL_CONNECTED) {
            ArduinoOTA.handle();
            server.handleClient();
        }
        vTaskDelay(10 / portTICK_PERIOD_MS); 
    }
}

// ═══════════════════════════════════════════
// CORE 0 TASK — Motor + Opto + LED display
// ═══════════════════════════════════════════
void realtimeTask(void* parameter) {
    ledcAttachChannel(MOTOR_PWM_PIN, PWM_FREQUENCY, PWM_RESOLUTION, PWM_CHANNEL);

    pinMode(MOTOR_DIR_PIN, OUTPUT);
    digitalWrite(MOTOR_DIR_PIN, HIGH);

    // Standard INPUT since we hardwired real 10k physical pull-ups 
    pinMode(OPTO1_PIN, INPUT);
    pinMode(OPTO2_PIN, INPUT);

    // Triggers when going from 3.3V (Blocked) to 0V (Clear)
    attachInterrupt(digitalPinToInterrupt(OPTO1_PIN), opto1ISR, FALLING);
    attachInterrupt(digitalPinToInterrupt(OPTO2_PIN), opto2ISR, FALLING);

    int testPhase = 0;
    unsigned long phaseStart = millis();

    while (true) {
        unsigned long now = millis();
        unsigned long elapsed = now - phaseStart;

        if (elapsed > 5000) {
            testPhase = (testPhase + 1) % 4;
            phaseStart = now;
        }

        switch (testPhase) {
            case 0:
                motorPWM = 102;
                ledcWrite(MOTOR_PWM_PIN, motorPWM);
                motorRunning = true;
                break;
            case 1:
                motorPWM = 178;
                ledcWrite(MOTOR_PWM_PIN, motorPWM);
                motorRunning = true;
                break;
            case 2:
                motorPWM = 255;
                ledcWrite(MOTOR_PWM_PIN, motorPWM);
                motorRunning = true;
                break;
            case 3:
                motorPWM = 0;
                ledcWrite(MOTOR_PWM_PIN, 0);
                motorRunning = false;
                break;
        }

        updateMatrix();
        vTaskDelay(100 / portTICK_PERIOD_MS);
    }
}

// ═══════════════════════════════════════════
// SETUP
// ═══════════════════════════════════════════
void setup() {
    Serial.begin(115200);

    matrix.begin();
    matrix.setBrightness(15);   
    matrix.clear();
    matrix.show();

    for (int i = 0; i < NUM_LEDS; i++) {
        matrix.setPixelColor(i, WHITE);
        matrix.show();
        delay(20);
    }
    delay(300);
    matrix.clear();
    matrix.show();

    xTaskCreatePinnedToCore(
        webTask,        
        "WebTask",      
        12000,          
        NULL,
        1,              
        &webTaskHandle,
        1               
    );

    xTaskCreatePinnedToCore(
        realtimeTask,
        "RealtimeTask",
        8000,
        NULL,
        2,              
        NULL,
        0               
    );
}

// ═══════════════════════════════════════════
// MAIN LOOP (Used strictly for diagnostic text)
// ═══════════════════════════════════════════
void loop() {
    // Print live status to the Serial Monitor (115200 baud)
    // You should see 1 when blocked, and 0 when clear.
    Serial.print("Opto 1 Pin Status: ");
    Serial.print(digitalRead(OPTO1_PIN));
    Serial.print("  |  Opto 2 Pin Status: ");
    Serial.println(digitalRead(OPTO2_PIN));
    
    vTaskDelay(200 / portTICK_PERIOD_MS);
}

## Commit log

2026-08-14 PCB Design, Firmware
2026-08-14 Updated the firmware ad hardware folders
    [Base.stl, Cover.stl, Crank Keeper.stl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]
2026-08-14 Added notes content for the failure of v1 of the cad
2026-08-15 Added content to the README file of the pcb
2026-08-15 Added the BOM file of the pre planned components
    [BOM-mvd_using_symech.xlsx]

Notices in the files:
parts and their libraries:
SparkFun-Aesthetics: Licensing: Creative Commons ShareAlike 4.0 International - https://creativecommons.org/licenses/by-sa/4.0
